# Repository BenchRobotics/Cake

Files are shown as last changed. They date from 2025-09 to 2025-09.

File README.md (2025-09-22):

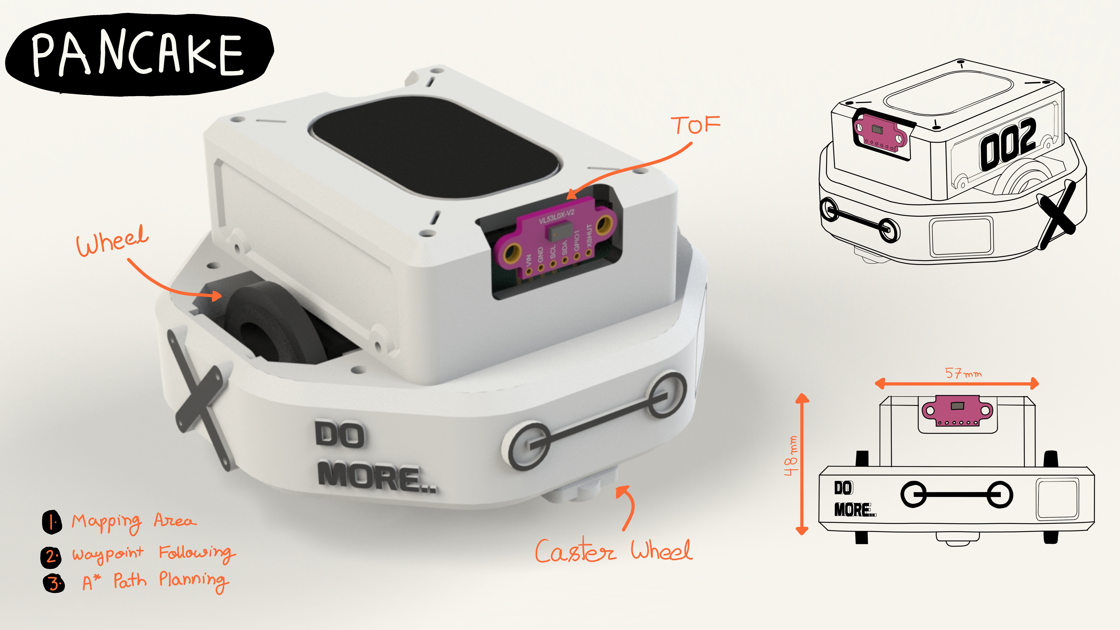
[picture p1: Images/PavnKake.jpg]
PavnKake


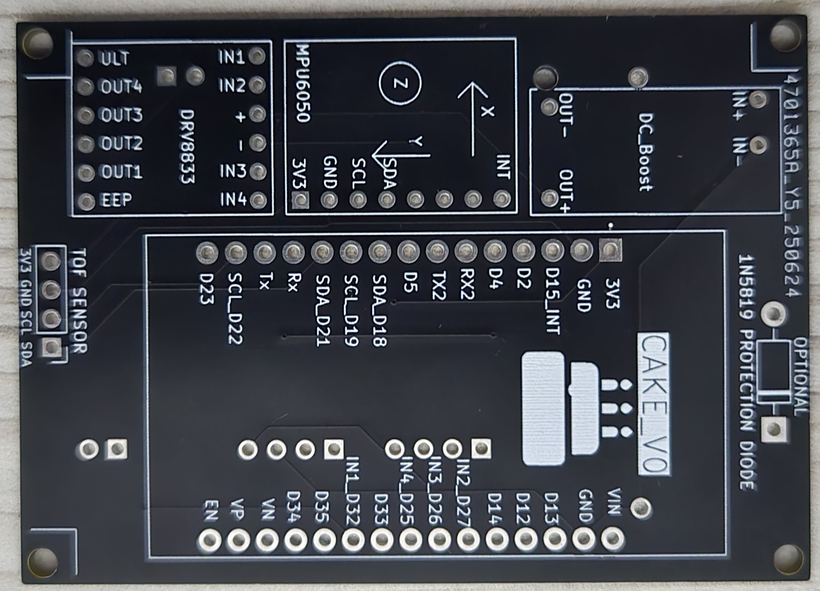
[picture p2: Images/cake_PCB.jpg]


## 🧾 Bill of Materials (BOM) for CAKEEVO PCB Project

| Component | Quantity | Description |
|---|---|---|
| ESP32 Dev Board | 1 | Main microcontroller (ESP32-WROOM-32 Devkit) |
| DRV8833 Motor Driver  | 1 | Dual motor driver breakout board |
| N20 Gear Motor | 2 | Compact DC motors for precise actuation |
| AS5600 Encoder | 2 | Magnetic rotary encoder for motor position feedback |
| MPU6050 Module | 1 | 6-axis IMU (accelerometer + gyroscope) |
| VL53L0X ToF Sensor | 1 | Time-of-flight distance sensor for obstacle detection |
| DC Boost Module | 1 | MT3608 voltage booster (e.g., 3.7V to 5V) |
| 16340 Battery | 1 | Rechargeable Li-ion battery for powering the system |
| Battery Holder | 1 | Compatible holder for 16340 battery |
| 1N5819 Diode | 1 | Schottky diode for reverse polarity protection |
| Male Pin Headers 90 degree | 40 pins | 2.54mm pitch, for module and I/O connections |
| Female Pin Headers | 40 pins | 2.54mm pitch, for module and I/O connections |
| 2mm x 10mm Screws | 20 | For mouting PCB and motors |
| Wires (Assorted) | — | Flexible hookup wires for connections |
| Soldering Iron Set | 1 | Basic soldering kit for assembly and repair |
| 3D  Printed parts | 1 | 3D pritned robot parts |

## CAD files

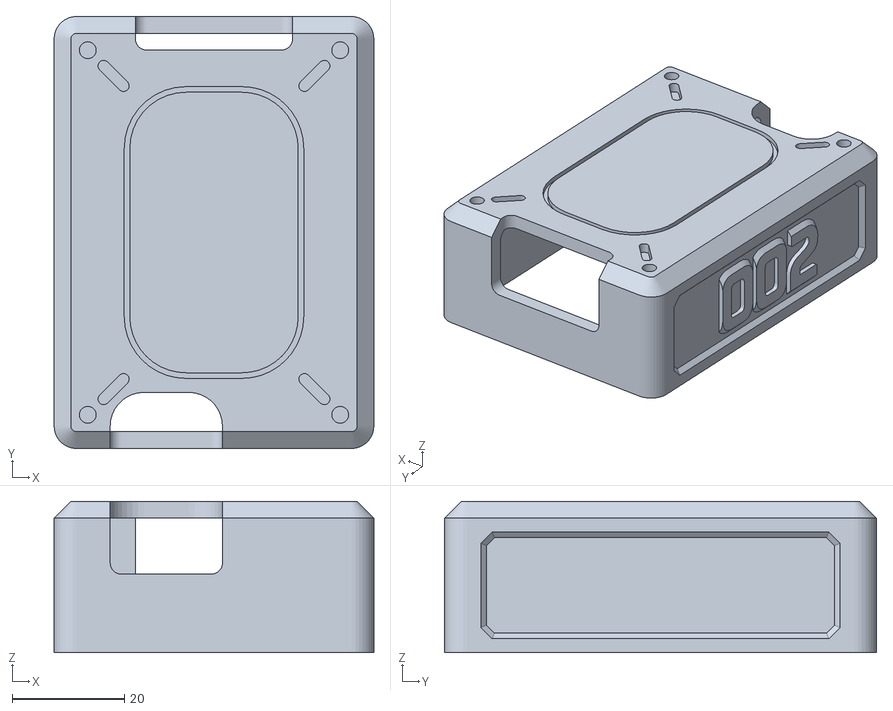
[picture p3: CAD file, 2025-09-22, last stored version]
CAD_FILES/PANCAKE_REV0_STL/Top_cove_v5.STL
57.0 x 77.0 x 27.0

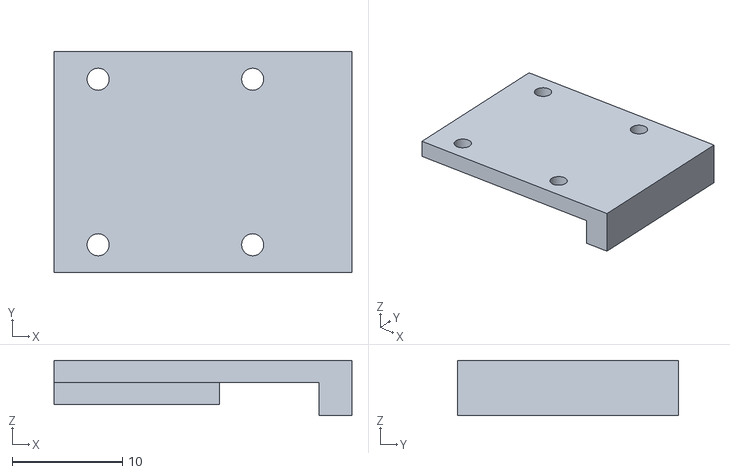
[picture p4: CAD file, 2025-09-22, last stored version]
CAD_FILES/PANCAKE_REV0_STL/motor_holder.STL
27.0 x 20.0 x 5.00

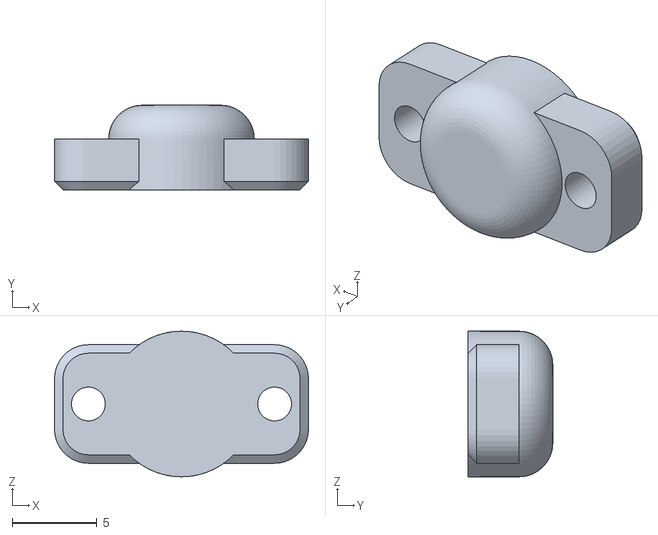
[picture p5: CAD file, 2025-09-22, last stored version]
CAD_FILES/PANCAKE_REV0_STL/Casterwheel.STL
15.0 x 5.00 x 8.60

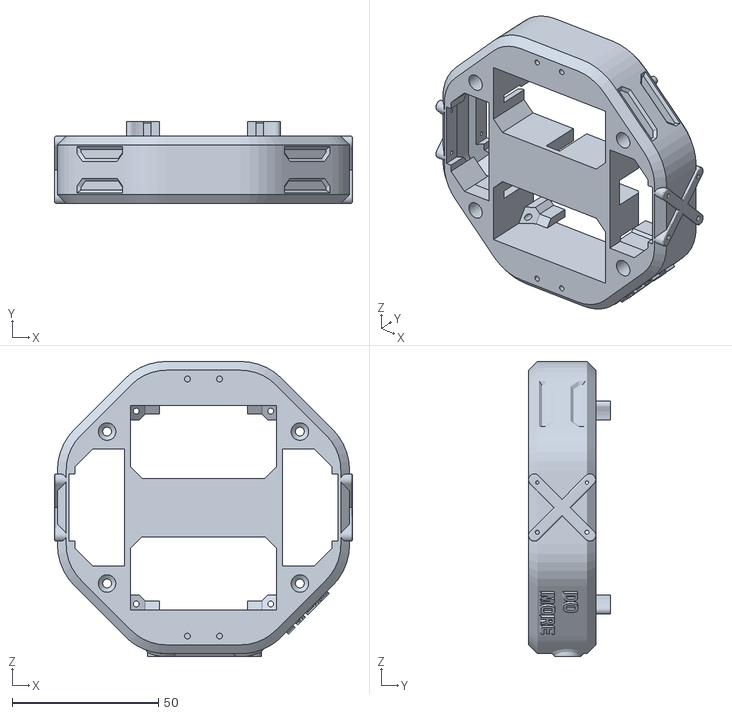
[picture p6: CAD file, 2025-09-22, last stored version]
CAD_FILES/PANCAKE_REV0_STL/chassis_v1_AS5600.STL
102.0 x 28.0 x 101.0

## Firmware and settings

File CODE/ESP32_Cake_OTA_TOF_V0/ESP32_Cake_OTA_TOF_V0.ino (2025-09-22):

#include <Wire.h>
#include <WiFi.h>
#include <WiFiUdp.h>
#include <ESPmDNS.h>
#include <ArduinoOTA.h>
#include <VL53L0X_mod.h>
#include "MPU6050_6Axis_MotionApps612.h"

#include "Cdrv8833.h"

#include "WheelOdometry.h"
#include "DataParser.h"

TwoWire I2Cone = TwoWire(0);
TwoWire I2Ctwo = TwoWire(1);

WheelOdometry leftWheel(&I2Cone);
WheelOdometry rightWheel(&I2Ctwo);

VL53L0X_mod sensor;

#define WIFI_SSID "ground"
#define WIFI_PASSWORD "12345678"
#define UDP_PORT 12345

//Motor Pins
#define IN1_PIN 32 //27
#define IN2_PIN 27  //32
#define RCHANNEL 0
#define IN3_PIN 26
#define IN4_PIN 25
#define LCHANNEL 1

DataParser dataParser;  // Create an instance of DataParse
const char* remoteIP = "192.168.1.11"; // Add your PC IP address

int DataIndex;
int L_Speed = 20;
int R_Speed = 20;
int Right_speed = 0;
int Left_speed = 0;
String movement;

WiFiUDP udp;

Cdrv8833 LMotor;
Cdrv8833 RMotor;

MPU6050 mpu(0x68, &I2Cone);

#define INTERRUPT_PIN 15 // use pin 15 for MPU interrupt

bool dmpReady = false;
uint8_t mpuIntStatus;
uint8_t devStatus;
uint16_t packetSize;
uint16_t fifoCount;
uint8_t fifoBuffer[64];

Quaternion q;
volatile bool mpuInterrupt = false;

float globalYaw = 0.0;
float globalPitch = 0.0;
float globalRoll = 0.0;
String globalOdom = "";
float globalDistance = 0.0;
String finalData = "";

bool headingKeepingEnabled = false;

float targetHeading = 0; // Target heading (in degrees)
float headingError = 0;  // Current heading error
float previousError = 0; // Error in the previous loop
float integral = 0;      // Integral term for PID
float kp = 5.0, ki = 0.00, kd = 0.0; // PID coefficients


void dmpDataReady() {
  mpuInterrupt = true;
}


void setup() {

  Serial.begin(115200);
  RMotor.init(IN1_PIN, IN2_PIN, LCHANNEL, true);
  LMotor.init(IN3_PIN, IN4_PIN, RCHANNEL, false);
  //Serial.println("ok");
  //_delay(750);
  I2Cone.begin(18,19, 400000UL);   //Scl,Sda
  I2Ctwo.begin(21,22, 400000UL); //22,21

  connectToWiFi();


    // Initialize MPU6050
  Serial.println("Initializing IMU device...");
  mpu.initialize();
  pinMode(INTERRUPT_PIN, INPUT);

  // Verify connection
  Serial.println("Testing device connections...");
  Serial.println(mpu.testConnection() ? "MPU6050 connection successful" : "MPU6050 connection failed");

  // Initialize DMP
  Serial.println("Initializing DMP...");
  devStatus = mpu.dmpInitialize();

  mpu.setXGyroOffset(51);
  mpu.setYGyroOffset(8);
  mpu.setZGyroOffset(21);
  mpu.setXAccelOffset(1150);
  mpu.setYAccelOffset(-50);
  mpu.setZAccelOffset(1060);

  if (devStatus == 0) {
    mpu.CalibrateAccel(6);
    mpu.CalibrateGyro(6);
    Serial.println("Enabling DMP...");
    mpu.setDMPEnabled(true);

    attachInterrupt(digitalPinToInterrupt(INTERRUPT_PIN), dmpDataReady, RISING);
    mpuIntStatus = mpu.getIntStatus();

    dmpReady = true;
    packetSize = mpu.dmpGetFIFOPacketSize();
    Serial.println("DMP ready!");
  } else {
    Serial.print("DMP Initialization failed (code ");
    Serial.print(devStatus);
    Serial.println(")");
  }

    //--------------
  ArduinoOTA
    .onStart([]() {
      String type;
      if (ArduinoOTA.getCommand() == U_FLASH)
        type = "sketch";
      else // U_SPIFFS
        type = "filesystem";

      // NOTE: if updating SPIFFS this would be the place to unmount SPIFFS using SPIFFS.end()
      Serial.println("Start updating " + type);
    })
    .onEnd([]() {
      Serial.println("\nEnd");
    })
    .onProgress([](unsigned int progress, unsigned int total) {
      Serial.printf("Progress: %u%%\r", (progress / (total / 100)));
    })
    .onError([](ota_error_t error) {
      Serial.printf("Error[%u]: ", error);
      if (error == OTA_AUTH_ERROR) Serial.println("Auth Failed");
      else if (error == OTA_BEGIN_ERROR) Serial.println("Begin Failed");
      else if (error == OTA_CONNECT_ERROR) Serial.println("Connect Failed");
      else if (error == OTA_RECEIVE_ERROR) Serial.println("Receive Failed");
      else if (error == OTA_END_ERROR) Serial.println("End Failed");
    });

  ArduinoOTA.begin();
  //-------------------------
  
  udp.begin(UDP_PORT);
  Serial.println("UDP Listening on port ");

    sensor.setBus(&I2Ctwo);
  sensor.setTimeout(500);
  
  
  if (!sensor.init())
  {
    Serial.println("Failed to detect and initialize sensor!");
    //while (1) {}
  }
  //sensor.startContinuous(200);

}


void loop() {
  ArduinoOTA.handle();
  process_imu();
  odom();
  //heading_control();
  measure_distance();
  data_to_send();
  udpReceiveTask();
}


void connectToWiFi() {
  WiFi.begin(WIFI_SSID, WIFI_PASSWORD);
    WiFi.setTxPower(WIFI_POWER_8_5dBm);//need for esp32c3
  Serial.print("Connecting to WiFi");

  while (WiFi.status() != WL_CONNECTED) {
    delay(500);
    Serial.print(".");
  }

  Serial.println("Connected to WiFi!");
  Serial.print("IP Address: ");
  Serial.println(WiFi.localIP());
}

void udpReceiveTask() {
  char packetBuffer[255];

  int packetSize = udp.parsePacket();
  if (packetSize) {
    int len = udp.read(packetBuffer, 255);
    if (len > 0) {
      packetBuffer[len] = 0;  // Null-terminate the string
      //Serial.println("Received UDP packet:");
      //Serial.println(packetBuffer);

      String IncomingData = packetBuffer;

      // --Library use --
      dataParser.parseData(IncomingData, ','); // Pass data and delimiter

      L_Speed = (dataParser.getField(1)).toInt();
      R_Speed = (dataParser.getField(2)).toInt();
      kp = (dataParser.getField(3)).toFloat();
      ki = (dataParser.getField(4)).toFloat();
      kd = (dataParser.getField(5)).toFloat();
      
      Left_speed = L_Speed;
      Right_speed = R_Speed;
      
      movement = (dataParser.getField(0));

        if(((dataParser.getField(7)).toInt()) == 1)
      {
        headingKeepingEnabled = true;
      }
      else
      {
        headingKeepingEnabled = false;
      }

      // Execute movement based on the parsed data
      if (movement == "f") {
        forward();
      } else if (movement == "b") {
        backward();
      } else if (movement == "l") {
        left();
      } else if (movement == "r") {
        right();
      } else if (movement == "s") {
        Stop();
      }
    }
  }
  delay(10);  // Small delay to avoid CPU overload
}

void motor_speed(int Right_Speed,int Left_Speed)
{
Left_speed = Left_Speed;
Right_speed = Right_Speed;
//Serial.println(Left_speed);
}
void forward()
{
  LMotor.move(Left_speed);
  RMotor.move(Right_speed);
  //Serial.println(Left_speed);
  targetHeading = globalYaw;
}
void backward()
{ 
  headingKeepingEnabled = false;
  LMotor.move(-Left_speed);
  RMotor.move(-Right_speed);
}
void right()
{  
  headingKeepingEnabled = false;
  LMotor.move(-Left_speed);
  RMotor.move(Right_speed);
}
void left()
{ 
  headingKeepingEnabled = false;
  LMotor.move(Left_speed);
  RMotor.move(-Right_speed);
}
void Stop()
{
  headingKeepingEnabled = false;
  LMotor.move(0);
  RMotor.move(0);
}


void odom()
{

   // Update odometry for both wheels
    leftWheel.update();
    rightWheel.update();

    // Get and print odometry data
    float leftOdometry = leftWheel.getOdometry();
    float rightOdometry = rightWheel.getOdometry();

    //Serial.print("Wheel 1 Odometry (radians): ");
    //Serial.print(leftOdometry);
    //Serial.print(",");
    //Serial.println(rightOdometry);

    //String Data = String(leftOdometry)+","+String(rightOdometry);
    globalOdom = String(leftOdometry)+","+String(rightOdometry);
    //transmit_data(Data);

    delay(20); // Small delay to reduce noise
  
}




void process_imu()
{
   if (!dmpReady) return;

  // Read a packet from FIFO
  if (mpu.dmpGetCurrentFIFOPacket(fifoBuffer)) {
    mpu.dmpGetQuaternion(&q, fifoBuffer);

    // Send quaternion data over UDP
   // Send quaternion data over UDP
   char dataBuffer[100];
   //snprintf(dataBuffer, sizeof(dataBuffer), "quat,%f,%f,%f,%f", q.w, q.x, q.y, q.z);
   
   udp.beginPacket(remoteIP, UDP_PORT);

   //udp.printf("%f,%f,%f,%f",q.w,q.x,q.y,q.z);// Sends the data over wifi
   //udp.write((uint8_t*)dataBuffer, strlen(dataBuffer)); // Cast char* to uint8_t*
  //udp.endPacket();


    // Debug output to Serial
    //Serial.println(dataBuffer);
/*
    Serial.print("quat\t");
    Serial.print(q.w);
    Serial.print("\t");
    Serial.print(q.x);
    Serial.print("\t");
    Serial.print(q.y);
    Serial.print("\t");
    Serial.println(q.z);
*/

      float yaw = getYaw(q);
    yaw = adjustYaw(yaw);
    
   globalYaw = yaw;//q.z;
    //Serial.println(q.z);
  }
}

void heading_control()
{
   if (headingKeepingEnabled) {
            headingError = targetHeading - globalYaw;

            // Ensure the error is within -180 to 180 degrees
           // if (headingError > 180) headingError -= 360;
           // if (headingError < -180) headingError += 360;

            // PID calculations
            integral += headingError;
            float derivative = headingError - previousError;
            float correction = kp * headingError + ki * integral + kd * derivative;
            previousError = headingError;

            // Adjust motor speeds
            int leftCorrection = (Left_speed - (correction*10));
            int rightCorrection = (Right_speed + (correction*10));
            Serial.println(leftCorrection);

            //motor_speed(leftCorrection, rightCorrection); // Adjusted motor speeds
             LMotor.move(leftCorrection);
             RMotor.move(rightCorrection);
            String Debug = String(globalYaw) + "," + String(targetHeading) + "," + String(headingError) + "," + String(correction);
            //Serial.println(Debug);
           //transmit_data(Debug);
        }
  
}
void transmit_data(String Data)
{       //String Data = "Hello";
        udp.beginPacket(remoteIP, UDP_PORT);
        udp.write((const uint8_t*)Data.c_str(), Data.length());
        udp.endPacket();
}
void data_to_send()
{
  finalData = globalOdom + "," + String(globalYaw) + "," + String(globalDistance);
  transmit_data(finalData);
}

void measure_distance()
{
   uint16_t NewMeasurement;
  //Serial.print(".");
  if(sensor.readRangeNoBlocking(NewMeasurement)){
      //Serial.println(".");
        Serial.println(NewMeasurement);
        globalDistance = NewMeasurement;
}
}
float getYaw(Quaternion q) {
    float w = q.w;
    float x = q.x;
    float y = q.y;
    float z = q.z;
    
    float sinr_cosp = 2 * (w * z + x * y);
    float cosr_cosp = 1 - 2 * (y * y + z * z);
    return atan2(sinr_cosp, cosr_cosp);
}
float adjustYaw(float yaw) {
    if (yaw < 0) {
        yaw += TWO_PI;
    }
    return yaw;
}

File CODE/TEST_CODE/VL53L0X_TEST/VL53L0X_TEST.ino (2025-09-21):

#include <Wire.h>
#include <Adafruit_VL53L0X.h>

// Create instances for the two I2C buses
TwoWire I2Ctwo = TwoWire(1);
Adafruit_VL53L0X lox = Adafruit_VL53L0X();

// Pin definitions
#define SDA_PIN 21
#define SCL_PIN 22

void setup() {
  // Start serial communication
  Serial.begin(115200);
  
  // Initialize I2C bus with custom pins
  I2Ctwo.begin(21, 22);

  // Initialize the sensor on the second I2C bus
  if (!lox.begin(0x29, true, &I2Ctwo)) {
    Serial.println(F("Failed to boot VL53L0X"));
    while (1);
  }
}

void loop() {
  VL53L0X_RangingMeasurementData_t measure;

  // Measure the distance
  lox.rangingTest(&measure, false); // Pass in 'true' to get debug data printout!

  // Check for errors
  if (measure.RangeStatus != 4) { // If there is no error
    Serial.print(F("Distance: "));
    Serial.print(measure.RangeMilliMeter);
    Serial.println(F(" mm"));
  } else {
    Serial.println(F("Out of range"));
  }

  // Delay between measurements
  delay(100);
}

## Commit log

2025-09-07 Add files via upload
    PCB files for fabrication
2025-09-21 Code to test sensors and connections
2025-09-22 Added BOM
2025-09-22 Pancake stl files
    [Casterwheel.STL, Top_cove_v5.STL, chassis_v1_AS5600.STL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]
